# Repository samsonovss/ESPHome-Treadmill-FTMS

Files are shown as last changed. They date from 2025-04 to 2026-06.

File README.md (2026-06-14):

# Smart ESPHome Treadmill with FTMS and Native Zwift Incline Control

[Русская версия](README.ru.md) | [Releases and history](https://github.com/samsonovss/ESPHome-Treadmill-FTMS/releases) | [Telegram community](https://t.me/TreadmillSmart)

Turn an older treadmill into a modern smart training machine. This project completely replaces the original console with an ESP32-S3 and ESPHome solution, controls the lower motor board directly over UART, and connects to Zwift and other fitness applications through Bluetooth [Fitness Machine Service (FTMS)](docs/specs/FTMS_v1.0.pdf) without bridges or companion apps. It supports native incline control from Zwift, Home Assistant, a Nextion display, heart-rate programs, built-in workout modes, and user-position and safety-zone detection with a VL53L1X laser time-of-flight distance sensor. The current configuration was developed for PSA(xx)-family boards but can be adapted to other treadmills after their control protocol has been investigated.

https://github.com/user-attachments/assets/f829769c-47f4-4251-8f99-d2f9a6cf358a

## Highlights

- **Direct Bluetooth FTMS** - no bridges or companion apps;
- **Native Zwift incline control** - route grade physically controls the treadmill;
- **Home Assistant integration**;
- **Custom Home Assistant workout automations** - create and run your own speed and incline programs;
- **Nextion touchscreen interface**;
- **Heart-rate workouts, HIIT, warm-up, and cool-down**;
- **ESPHome-based and fully local** - no cloud required;
- **Laser ToF safety-zone detection, optical speed feedback, and motor-temperature monitoring**.

## Architecture

```mermaid
flowchart LR
    Apps[Zwift / Kinomap / other FTMS apps]
    HA[Home Assistant]
    HR[BLE heart-rate monitor]
    ESP[ESP32-S3 + ESPHome]
    Display[Nextion]
    Sensors[VL53L1X / FC-33 / DS18B20]
    Board[Treadmill motor controller]

    Apps <-->|BLE FTMS / RSC| ESP
    HA <-->|ESPHome API| ESP
    HR -->|BLE Heart Rate| ESP
    Display <-->|UART| ESP
    Sensors --> ESP
    ESP <-->|UART SETSPD / SETINC| Board
```

The ESP32-S3 acts as the central controller. It receives commands from the UI, workout programs, or fitness apps, sends them to the treadmill motor controller, and publishes telemetry back to Home Assistant and BLE clients.

## Supported Applications

Tested applications:

- **Zwift**
- **Kinomap** on Android and iOS
- **FitShow**
- **Kinni**

Other FTMS applications may behave differently. FTMS support alone does not guarantee that every application uses the same characteristics and control commands.

### Application Compatibility Matrix

| Feature | Zwift | Kinomap | FitShow | Kinni |
|---|---:|---:|---:|---:|
| Treadmill discovery over BLE | ✅ | ✅ | ✅ | ✅ |
| Speed reporting | ✅ | ✅ | ✅ | ✅ |
| Distance reporting | ✅ | ✅ | ✅ | ✅ |
| Heart-rate reporting | ✅ | ✅ | ✅ | ✅ |
| Start / pause / stop from the application | ➖ | ✅ | ✅ | ✅ |
| Target-speed control from the application | ➖ | ✅ | ✅ | ✅ |
| Incline control from the application | ➖ | ✅ | ✅ | ✅ |
| Automatic route-grade incline control | ✅ | ✅ | ✅ | ✅ |
| Native Zwift route-grade incline control | ✅ | ➖ | ➖ | ➖ |

✅ — tested and working; ➖ — not applicable.

> This matrix reflects practical testing with the current firmware version. Behavior may depend on the application version.

### FTMS and Zwift Compatibility

For standard fitness applications, the treadmill uses Bluetooth FTMS to report workout data and control speed and incline.

Native automatic incline in Zwift additionally uses a Wahoo KICKR RUN compatibility profile. Zwift sends route grade through the proprietary Wahoo Run service rather than through the standard FTMS incline-control command.

Therefore:

- standard FTMS provides primary compatibility with Zwift, Kinomap, FitShow, Kinni, and other applications;
- the Wahoo KICKR RUN profile provides native route-grade incline control in Zwift.

## Zwift Automatic Incline

The project supports two independent incline modes:

1. **Native Zwift incline**: the current route grade is received directly from Zwift and mapped to the treadmill's physical incline level.
2. **Standalone route profiles**: saved elevation profiles can run without the Zwift application.

Native mode provides:

- `Zwift Auto Incline` to enable physical incline control;
- `Treadmill Maximum Incline Level` for the treadmill controller limit;
- `Treadmill Real Grade At Maximum` for the measured real grade at that level;
- `Zwift Incline Intensity` for a 0-100% effect strength;
- `Zwift Requested Incline` for the grade received from Zwift;
- `Zwift Mapped Treadmill Incline` for the resulting treadmill target.

A treadmill value of `15` does not necessarily mean a real `15%` grade. Measure the actual belt rise and calibrate the mapping before enabling automatic incline.

See [Zwift setup and incline calibration](docs/guides/ZWIFT.md).

<details>
  <summary><b>Zwift demonstration</b></summary>
  <p align="center">
    Treadmill connected to Zwift
  </p>
</details>

## Treadmill Compatibility

The current configuration was developed for a treadmill with a PSA(xx)-family motor board accepting commands such as:

```text
[SETSPD:010]  -> 1.0 km/h
[SETINC:050]  -> incline level 5.0
```

Another treadmill can be adapted when its control interface is accessible, but the presence of UART does not make it automatically compatible. Voltage levels, baud rate, packet format, commands, feedback, and safe limits must be identified first.

See the [UART parsing guide](docs/guides/UART_PARSING.md).

> [!IMPORTANT]
> Reverse-engineering the control protocol is usually the most difficult part of adapting this project to another treadmill board.

## Hardware

Core components:

- ESP32-S3 with PSRAM and 16 MB Flash;
- treadmill with access to the lower motor controller interface;
- bidirectional logic-level converter;
- step-down power converter;
- Nextion `NX4880E043-011C`, 4.3-inch, 800 x 480 display;
- BLE heart-rate monitor.

Optional components:

- VL53L1X/TOF400C for Free Run, safe-zone detection, and display control;
- FC-33 for real-speed measurement and correction;
- DS18B20 for motor temperature monitoring;
- 3D-printed enclosure and mounts.

<details>
  <summary><b>Component photos</b></summary>
  <p align="center">
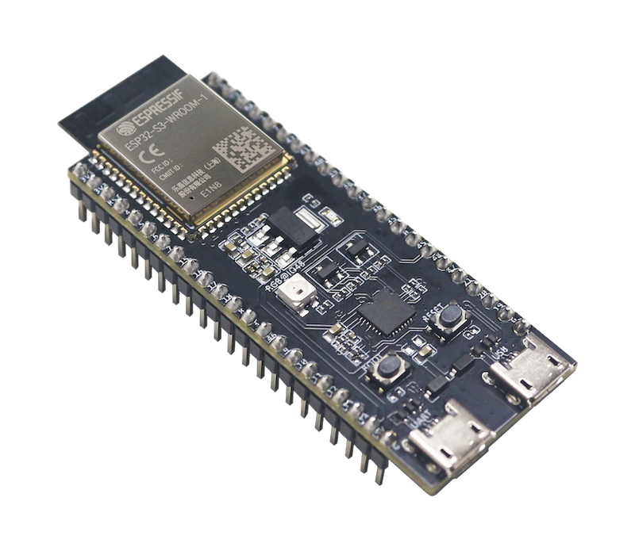
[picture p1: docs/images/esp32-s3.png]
ESP32-S3
    
    Nextion display
    VL53L1X
  </p>
  <p align="center">
    Logic-level converter
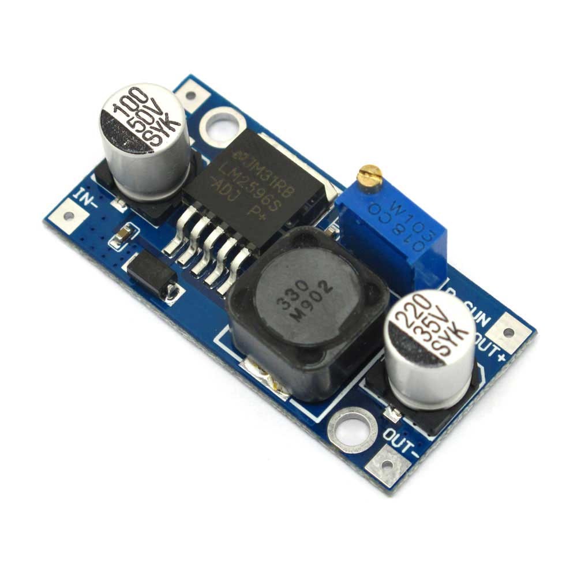
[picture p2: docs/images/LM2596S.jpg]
LM2596S step-down converter
    
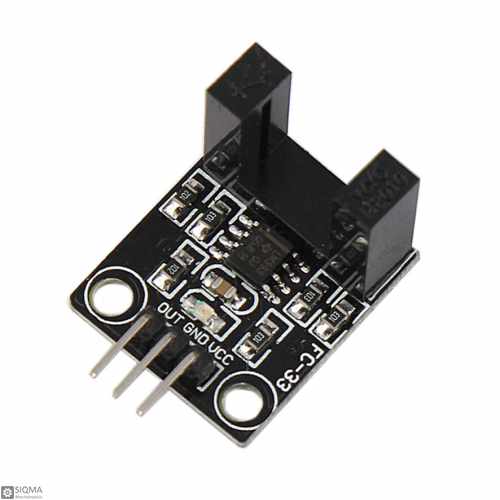
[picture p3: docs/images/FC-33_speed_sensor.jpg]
FC-33 optical sensor
    
  </p>
</details>

## Wiring

<p align="center">
  ESP32-S3 treadmill wiring diagram
</p>

Pins used by the current configuration:

| Function | ESP32-S3 |
|---|---|
| Nextion RX/TX | GPIO1 / GPIO2 |
| Treadmill board TX/RX | GPIO17 / GPIO18 |
| I2C SDA/SCL | GPIO12 / GPIO11 |

Verify the voltage levels of your motor board before connecting it. Never feed 5 V or 12 V directly into ESP32-S3 GPIO pins.

## Quick Start

1. Download the repository and copy the contents of `esphome/` into your ESPHome configuration directory.
2. Rename `secrets.example.yaml` to `secrets.yaml`.
3. Configure Wi-Fi, API, OTA, fallback access point, DS18B20 address, heart-rate monitor MAC, and Nextion TFT URL.
4. Keep the `packages/` directory next to `config.yaml`; the main file loads all functional sections from it.
5. Verify pin assignments, UART settings, and the command format used by your treadmill.
6. Disconnect the power stage and first test ESP32 boot, Nextion, and sensors.
7. Create a backup, compile the configuration, and inspect the logs.
8. Test stop behavior, minimum speed, and incline reset without a person on the belt.

The configuration is a working example for one installation, not a universal firmware image for every treadmill.

## Workout Modes

- manual control;
- Pulse Zone;
- Fat Burn;
- Recovery Run;
- configurable HIIT work and recovery cycles;
- warm-up and cool-down;
- distance-based Free Run;
- precomputed route elevation profiles;
- native Zwift incline control.

Configurable treadmill behavior profiles:

- **Speed correction:** `Soft`, `Precise`, and `Aggressive` control how actively the system compensates for differences between the target and measured belt speed;
- **Acceleration and deceleration:** `Soft`, `Normal`, `Fast`, and `Technogym` control how smoothly and quickly the belt changes speed.

## Interfaces

The local ESPHome web interface is available on port `80` without authentication.

Workout recording to CSV and Garmin FIT is available through the optional [Home Assistant workout recorder](treadmill_workouts/README.md).

### Home Assistant

<p align="center">
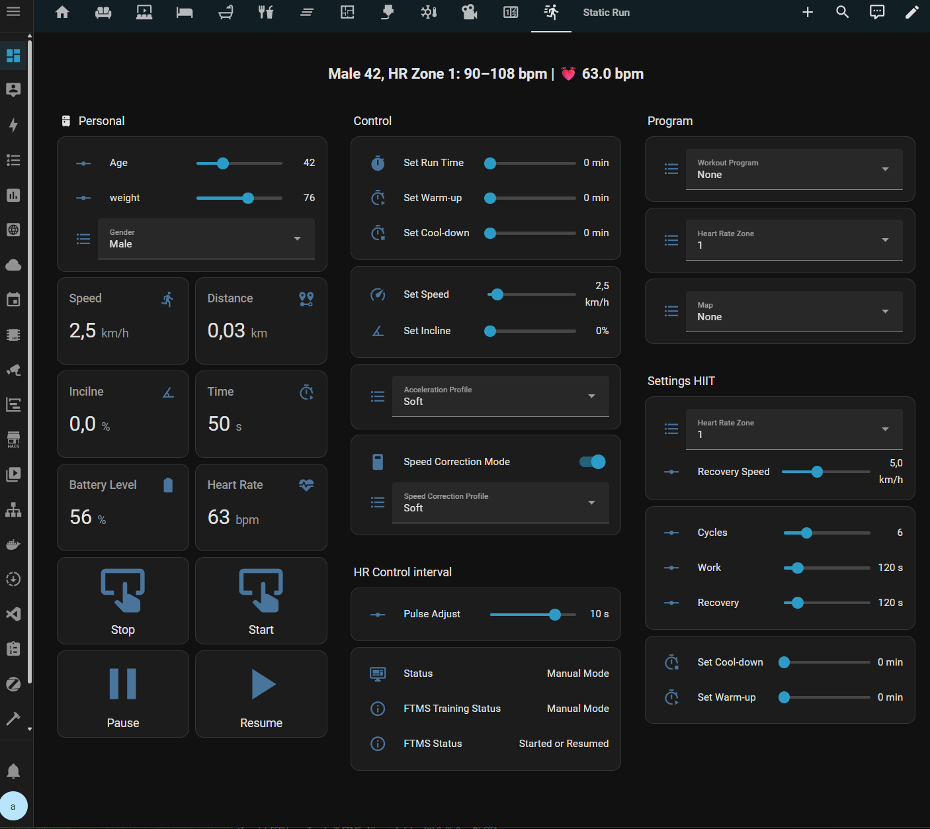
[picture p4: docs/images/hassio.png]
Home Assistant treadmill control interface
  
</p>

<details>
  <summary><b>Nextion</b></summary>
  <p align="center">
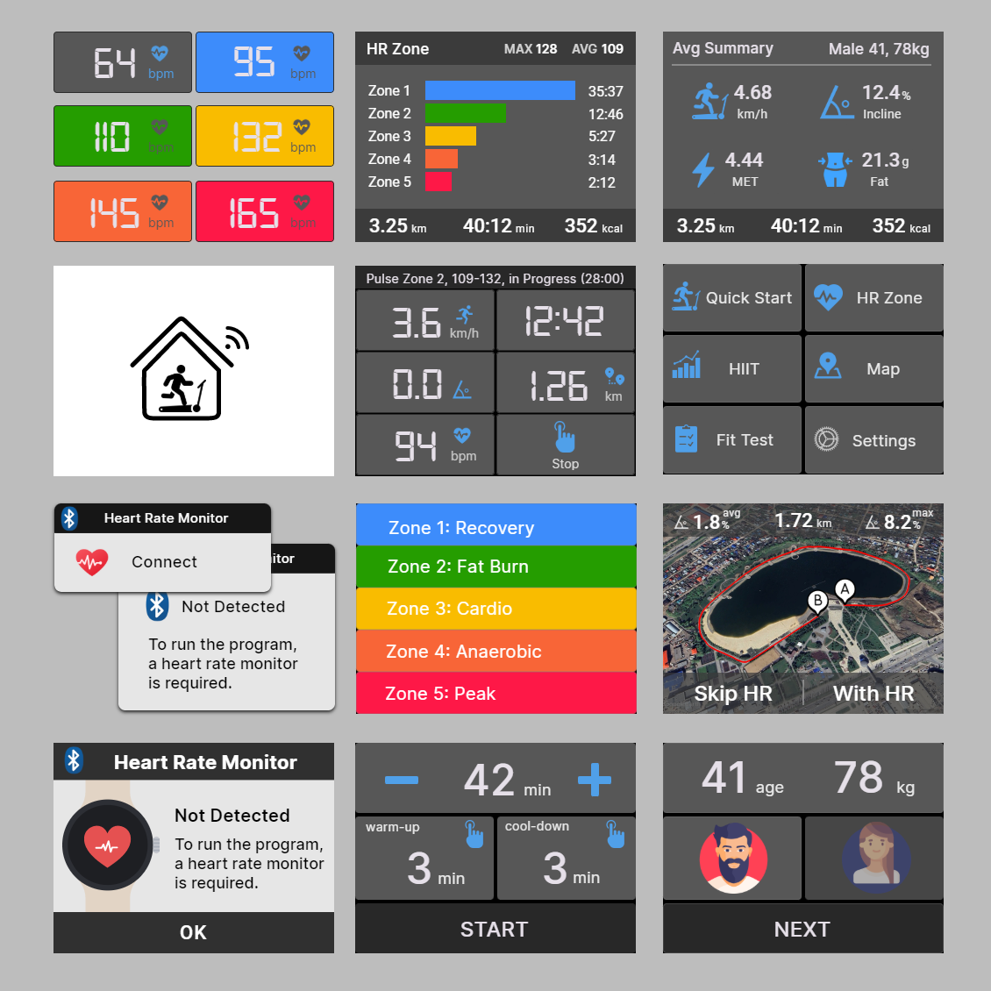
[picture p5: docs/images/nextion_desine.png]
Nextion display interface
    
  </p>
</details>

<details>
  <summary><b>Finished treadmill gallery</b></summary>
  <p align="center">
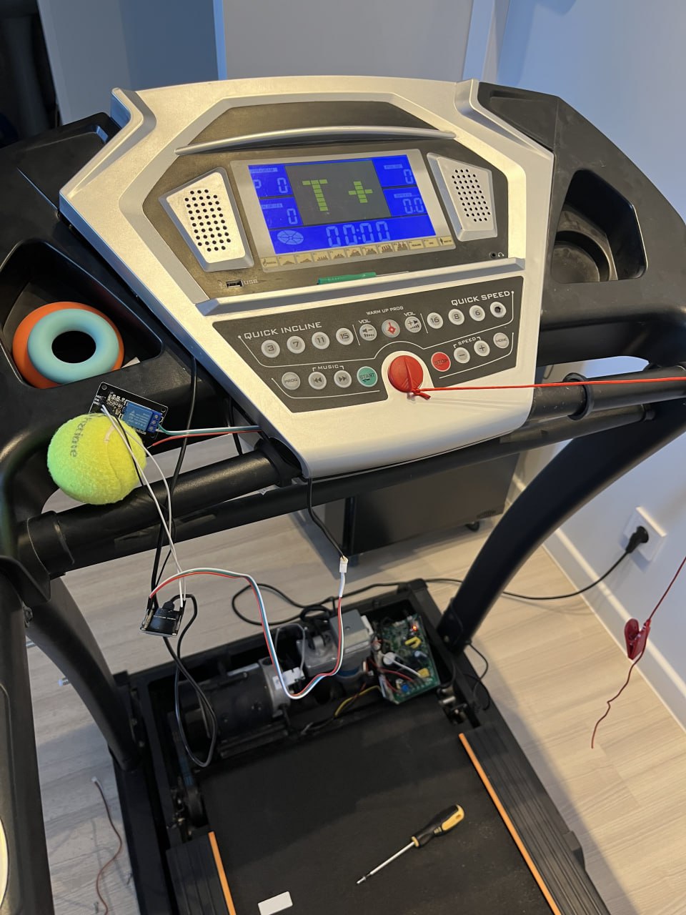
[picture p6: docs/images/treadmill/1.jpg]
Finished treadmill, view 1
    
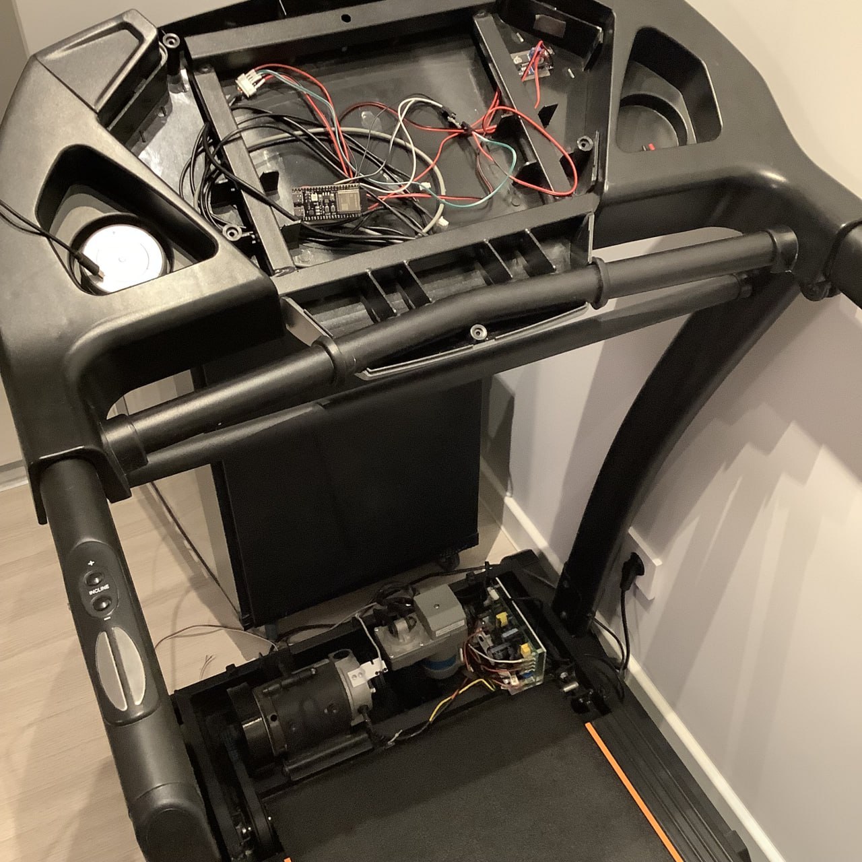
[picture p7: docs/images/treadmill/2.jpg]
Finished treadmill, view 2
    
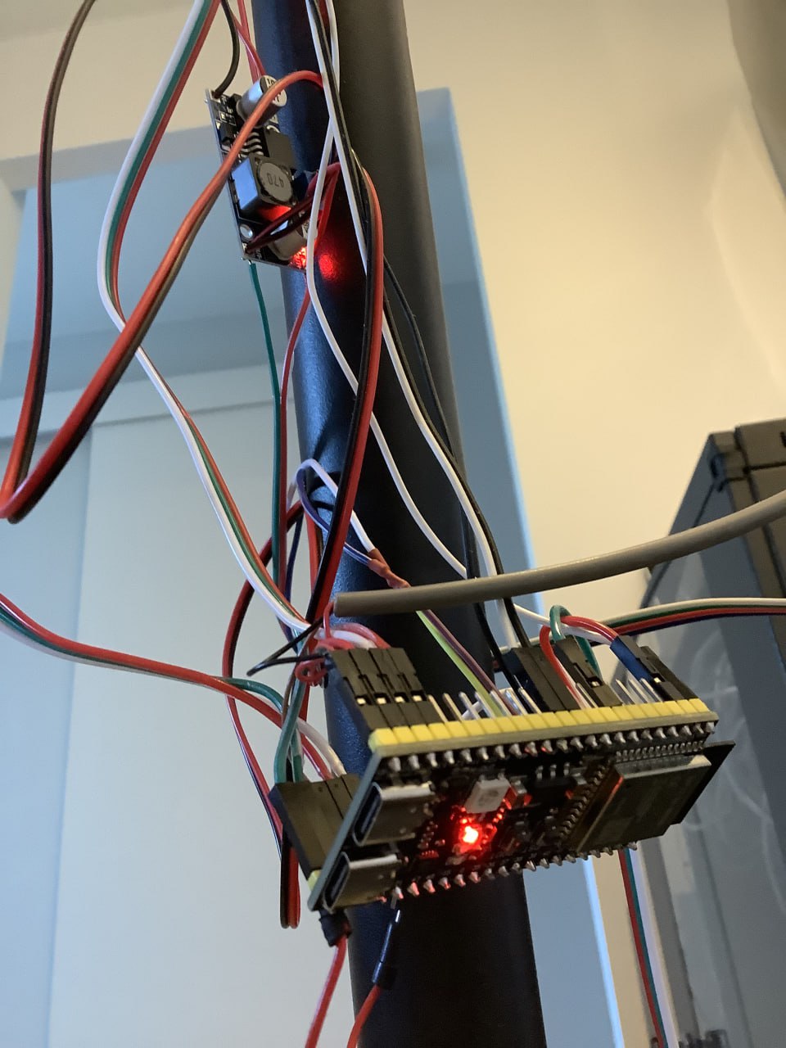
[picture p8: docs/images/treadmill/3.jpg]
Finished treadmill, view 3
    
  </p>
  <p align="center">
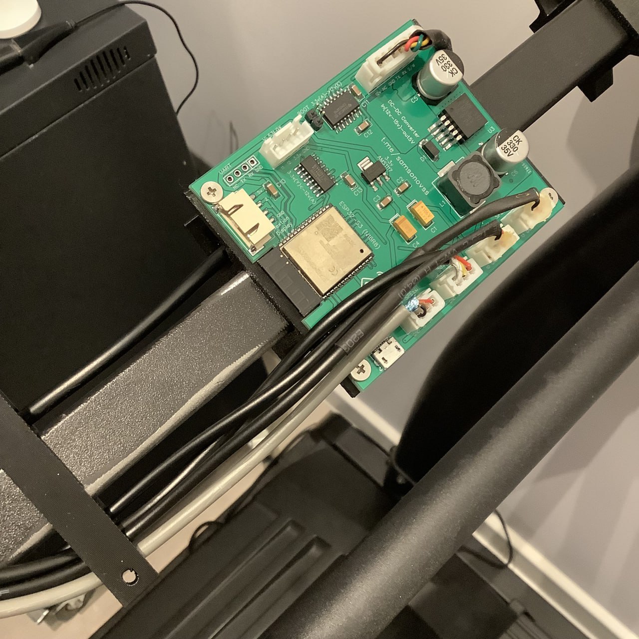
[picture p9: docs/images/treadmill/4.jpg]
Finished treadmill, view 4
    
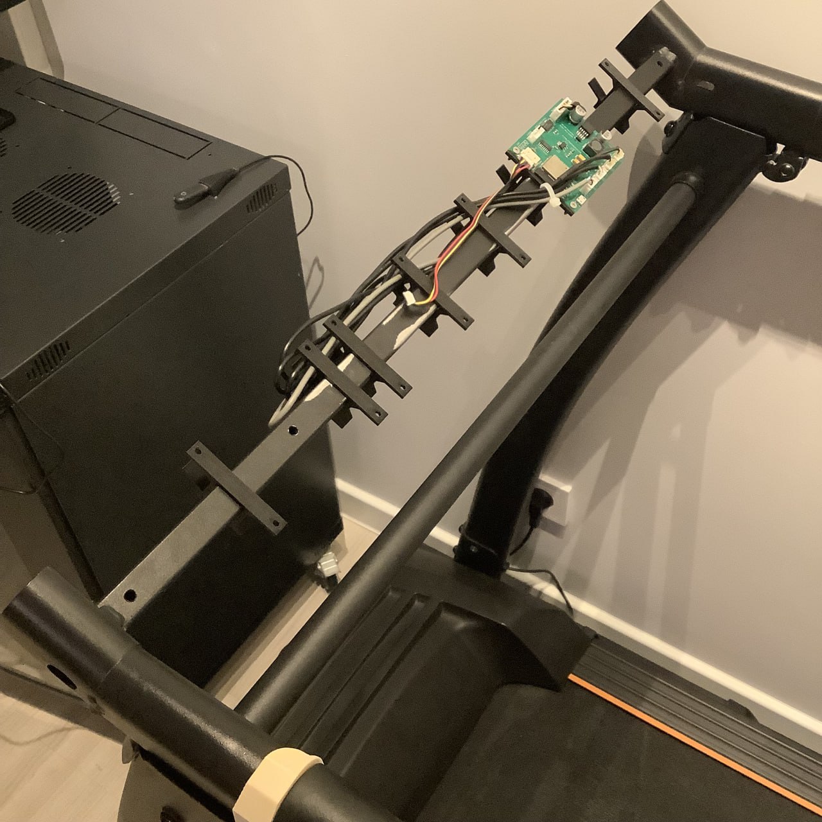
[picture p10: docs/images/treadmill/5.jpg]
Finished treadmill, view 5
    
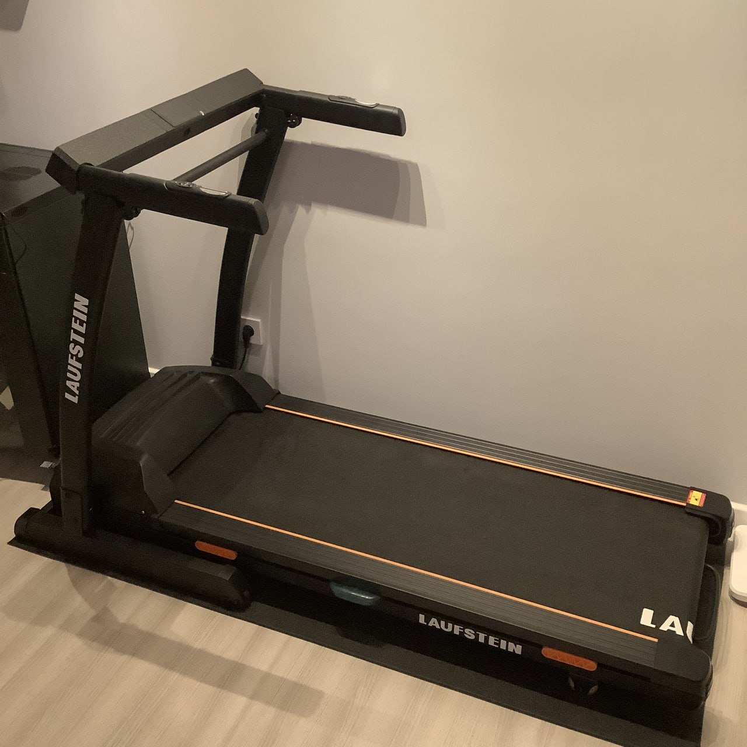
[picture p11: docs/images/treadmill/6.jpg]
Finished treadmill, view 6
    
  </p>
</details>

Videos:

- [control dashboard overview](https://youtube.com/shorts/wjRsA46usog);
- [treadmill running demonstration](https://youtube.com/shorts/QqvJLKn4GOk).

## Repository Layout

- [`esphome/config.yaml`](esphome/config.yaml) - main device configuration with ESP32, network, API, OTA, BLE, and package declarations;
- [`esphome/packages/`](esphome/packages/) - hardware, globals, scripts, sensors, BLE/FTMS, controls, and Nextion configuration;
- [`esphome/incline_profiles.h`](esphome/incline_profiles.h) - generated route incline profiles;
- [`treadmill_workouts/`](treadmill_workouts/) - Home Assistant CSV recorder and FIT exporter;
- [`nextion_display/`](nextion_display/) - display source, HMI, and compiled TFT;
- [`route_profiles/`](route_profiles/) - optional GPX sources, saved route profiles, and profile-generation tools;
- [`3d-models/`](3d-models/) - printable enclosure and sensor mounts;
- [`PCB/`](PCB/) - future PCB design materials;
- [`docs/guides/`](docs/guides/) - detailed setup guides;
- [`docs/specs/FTMS_v1.0.pdf`](docs/specs/FTMS_v1.0.pdf) - FTMS specification;
- [GitHub Releases](https://github.com/samsonovss/ESPHome-Treadmill-FTMS/releases) - versions and project history.

## Roadmap

- cadence measurement.
- feasibility study for a custom lower power board controlling the treadmill motor and incline.

Completed work is removed from the roadmap and recorded in the [release notes](https://github.com/samsonovss/ESPHome-Treadmill-FTMS/releases).

## Support the Project

This project is developed in the author's free time and has so far been funded personally. Firmware and electronics development, prototype manufacturing, components, and testing require significant time and expense.

If this project has been useful to you and you would like to support its continued development, any contribution will help fund new components, prototypes, test equipment, and documentation.

## Author and Community

Created by [Anton Samsonov](https://t.me/samsonovss).

Discussion, builds, and support: [Treadmill Smart](https://t.me/TreadmillSmart).

## Support the Project

- PayPal: `samsonov@hotmail.com`
- BTC: `bc1q3cza0kasutzes4hfddxuclmd9ghn5v7zw2nr5c`

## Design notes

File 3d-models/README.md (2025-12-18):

# 3D Printed Enclosure

This folder contains the 3D model of the enclosure and the small mounting parts used for installing the speed‑sensor module.

<p align="center">
  
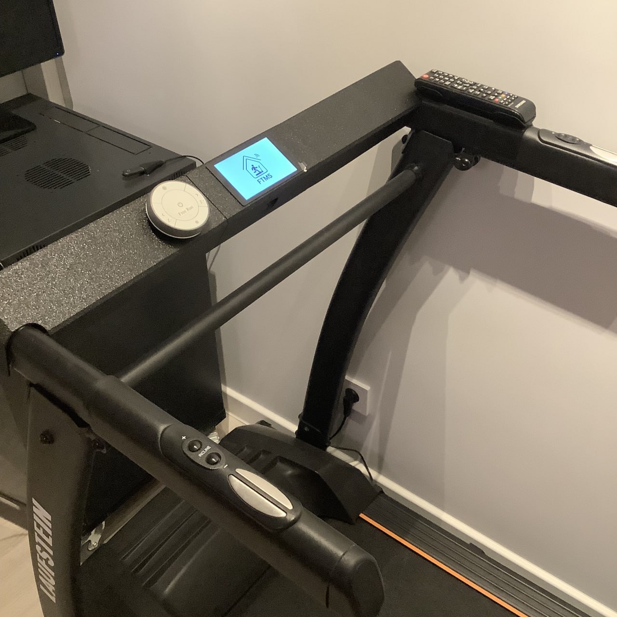
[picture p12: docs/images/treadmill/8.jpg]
  
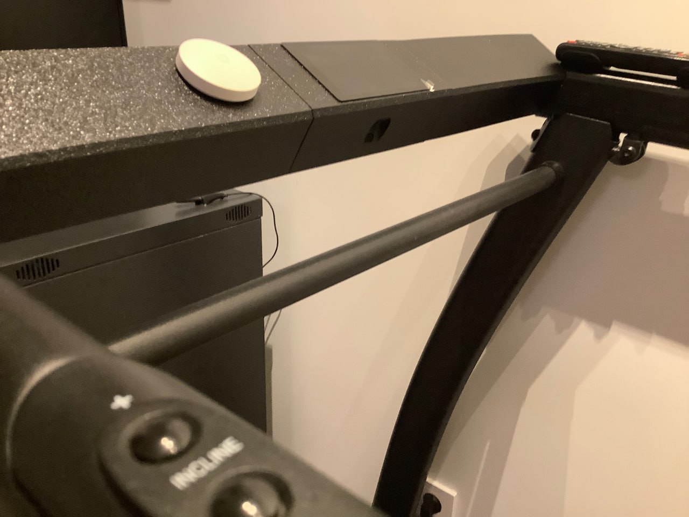
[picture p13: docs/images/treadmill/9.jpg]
  
</p>

## 🎯 Design Philosophy

The goal of this project was to create a clean, minimalist enclosure instead of the bulky, outdated “modern” designs commonly found in treadmill accessories.  
The envisioned setup includes a sleek control panel with a display, an optional tablet mount with wireless charging, and a large wall‑mounted TV for training apps — all designed to look simple, elegant, and unobtrusive.

## 📦 Enclosure Overview

The design consists of three separate parts, which are assembled together and mounted on top of the treadmill’s control module.

In the lower section of the enclosure, a distance sensor is installed.  
It enables the free‑run mode, automatically activates the display, and controls the treadmill speed based on the measured distance.

Under the top panel, a magnet is permanently fixed, allowing you to attach any magnetic button on top of the enclosure.  
You can program this button for any custom action depending on your ESPHome configuration.

The enclosure is planned to support additional upgrades in future revisions, such as:

- a tablet mount installed on top of the enclosure  
- a wireless charging pad placed underneath the tablet holder  

These features will be useful if you want to use a tablet for Zwift, YouTube, or other training applications.

## ⚠️ Design Status

The current STEP model is not fully finished.  
At this stage, the enclosure does not yet include the bottom cover.  
These components will be added in future revisions of the design.

## 🖨️ 3D Printing Details

- Printed on Bambu Lab A1  
- Print area used: 256 × 256 × 256 mm  
- Surface printed using fuzzy skin

## 🎨 Finishing (Optional)

If desired, the enclosure can be:

- sanded  
- primed  
- painted  

This allows you to achieve a smooth, durable, and professional‑looking finish.

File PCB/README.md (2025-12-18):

## PCB Design for ESPHome Treadmill-Zwift

This directory is intended to store the design files and documentation for the future custom printed circuit board (PCB) for the ESPHome Treadmill-Zwift project, which will be developed using EasyEDA.

<p align="center">
  
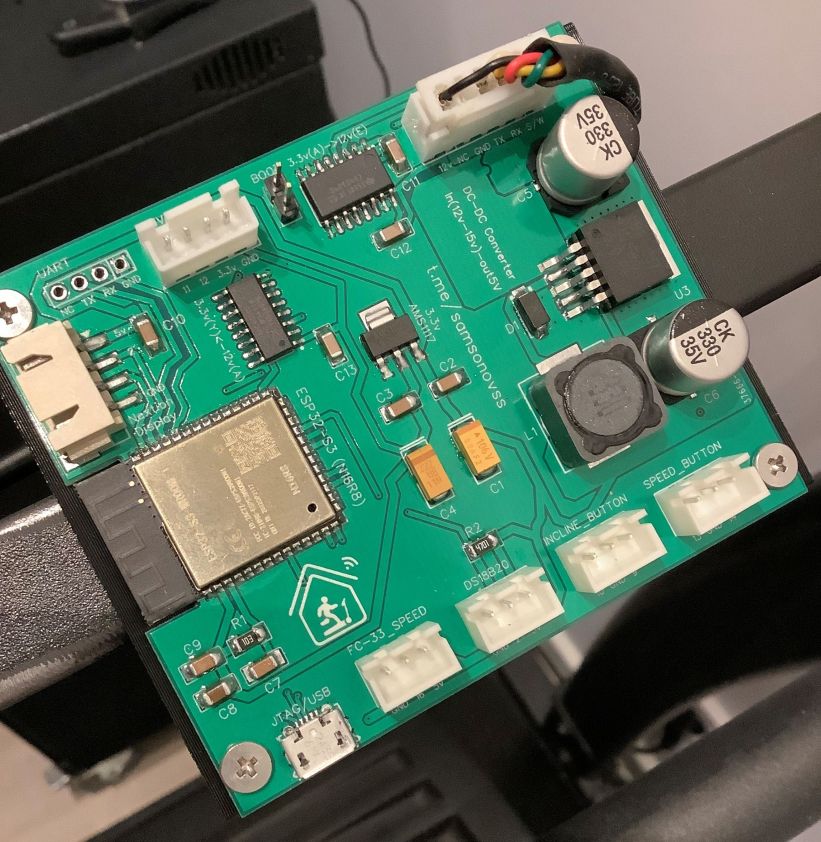
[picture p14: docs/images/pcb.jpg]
  
</p>

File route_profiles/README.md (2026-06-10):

# Route Profiles

[Русская версия](README.ru.md)

This directory contains source route data and development tools used to prepare
autonomous treadmill incline profiles.

It is **not required for a normal ESPHome installation**. The profiles used by
the firmware are already stored in [`esphome/incline_profiles.h`](../esphome/incline_profiles.h).

## Directory Layout

```text
route_profiles/
├── gpx_files/       # Source GPX routes with distance and elevation waypoints
├── scripts/         # GPX conversion tools
└── zwift_profiles/  # Saved Zwift route profiles and generated C++ snippets
```

## Preparing a Route

1. Create or export a route as KML or GPX.
2. If elevation data is missing, process it with
   [GPS Visualizer](https://www.gpsvisualizer.com/convert_input):
   - output format: `GPX`;
   - DEM elevation data: `Best available source`;
   - equal-interval waypoints: `30 meters`.
3. Save the result in `route_profiles/gpx_files/`.
4. Run the converter from the repository root:

   ```sh
   python3 route_profiles/scripts/gpx_to_incline_profile.py \
     route_profiles/gpx_files/example.gpx \
     --name example_route
   ```

By default, the generated C++ profile is written next to the input file as
`example.profile.h`. Use `--output` to choose another path.

The generated file contains a two-dimensional ESPHome profile:

```cpp
const float incline_profile_example_route[][2] PROGMEM = {
  {0.000, 0},
  {0.030, 3},
};
```

The first value is route distance in kilometres. The second value is the
treadmill incline level.

## Calibration

The default conversion assumes:

```text
maximum treadmill level = 15
real grade at maximum = 5%
```

Override these values when your treadmill uses different limits:

```sh
python3 route_profiles/scripts/gpx_to_incline_profile.py \
  route_profiles/gpx_files/example.gpx \
  --name example_route \
  --maximum-level 15 \
  --real-grade-at-maximum 5
```

Review the generated profile before copying it into
`esphome/incline_profiles.h`. The converter intentionally never overwrites the
firmware profile file automatically.

## GPX Requirements

The converter expects GPX waypoints containing:

- an `<ele>` elevation value;
- a `<name>` beginning with distance in metres and containing the word
  `distance`.

GPS Visualizer can create waypoints in this format.

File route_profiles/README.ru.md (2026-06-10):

# Профили маршрутов

[English version](README.md)

Этот каталог содержит исходные маршруты и инструменты разработки для
подготовки автономных профилей наклона беговой дорожки.

Для обычной установки ESPHome он **не требуется**. Готовые профили, которые
использует прошивка, уже находятся в
[`esphome/incline_profiles.h`](../esphome/incline_profiles.h).

## Структура

```text
route_profiles/
├── gpx_files/       # Исходные GPX с точками дистанции и высоты
├── scripts/         # Инструменты преобразования GPX
└── zwift_profiles/  # Сохранённые профили Zwift и фрагменты C++
```

## Подготовка маршрута

1. Создайте или экспортируйте маршрут в KML либо GPX.
2. Если в файле нет высоты, обработайте его через
   [GPS Visualizer](https://www.gpsvisualizer.com/convert_input):
   - формат результата: `GPX`;
   - данные высоты DEM: `Best available source`;
   - точки с равным интервалом: `30 meters`.
3. Сохраните результат в `route_profiles/gpx_files/`.
4. Запустите конвертер из корня репозитория:

   ```sh
   python3 route_profiles/scripts/gpx_to_incline_profile.py \
     route_profiles/gpx_files/example.gpx \
     --name example_route
   ```

По умолчанию рядом с исходным файлом будет создан
`example.profile.h`. Другой путь можно указать через `--output`.

Результат имеет тот же двумерный формат, который использует ESPHome:

```cpp
const float incline_profile_example_route[][2] PROGMEM = {
  {0.000, 0},
  {0.030, 3},
};
```

Первое значение — пройденная дистанция в километрах, второе — уровень наклона
дорожки.

## Калибровка

По умолчанию используется соответствие:

```text
максимальный уровень дорожки = 15
реальный уклон на максимуме = 5%
```

Для другой дорожки задайте собственные значения:

```sh
python3 route_profiles/scripts/gpx_to_incline_profile.py \
  route_profiles/gpx_files/example.gpx \
  --name example_route \
  --maximum-level 15 \
  --real-grade-at-maximum 5
```

Проверьте созданный профиль перед переносом в
`esphome/incline_profiles.h`. Конвертер специально не перезаписывает рабочий
файл прошивки автоматически.

## Требования к GPX

Конвертер ожидает точки `<wpt>`, содержащие:

- высоту в поле `<ele>`;
- поле `<name>`, которое начинается с дистанции в метрах и содержит слово
  `distance`.

Такие точки умеет создавать GPS Visualizer.

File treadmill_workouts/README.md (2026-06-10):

# Treadmill Workout Recorder

This optional Home Assistant companion records treadmill workouts to CSV and exports a Garmin FIT activity after each workout.

## How It Works

1. A Home Assistant automation starts `treadmill_recorder.py` when `binary_sensor.treadmill_treadmill_usage` turns on.
2. The recorder reads treadmill entities from the local Home Assistant REST API once per second.
3. Samples are written to a timestamped CSV file.
4. When the treadmill stops, the recorder writes a summary JSON file.
5. `treadmill_fit_export.py` converts the CSV and summary into a FIT running activity with treadmill sub-sport.

The FIT exporter uses only the Python standard library. It writes timestamps, heart rate, speed, distance, incline/grade, calories, lap, session, and activity summaries.

## Directory Layout

```text
/config/treadmill_workouts/
├── scripts/
│   ├── treadmill_recorder.py
│   └── treadmill_fit_export.py
├── secrets/
│   └── .ha_token
├── workouts/
├── logs/
└── state/
```

The repository contains empty runtime directories. Tokens, logs, state files, and personal workout exports are excluded by `.gitignore`.

## Installation

1. Copy `treadmill_workouts/` to `/config/treadmill_workouts/` in Home Assistant.
2. Make the scripts executable:

   ```sh
   chmod 755 /config/treadmill_workouts/scripts/*.py
   ```

3. In the Home Assistant user profile, create a long-lived access token.
4. Save only the token value to:

   ```text
   /config/treadmill_workouts/secrets/.ha_token
   ```

5. Restrict access to the token:

   ```sh
   chmod 600 /config/treadmill_workouts/secrets/.ha_token
   ```

6. Merge [`examples/configuration.yaml`](examples/configuration.yaml) into `configuration.yaml`.
7. Add [`examples/automations.yaml`](examples/automations.yaml) through YAML or recreate the three automations in the Home Assistant UI.
8. Check the configuration and restart Home Assistant.

## Configuration

Edit these constants in `scripts/treadmill_recorder.py` when your installation uses different values:

- `BASE_URL` - local Home Assistant URL;
- `ROOT` - recorder directory;
- `TZ` - workout timezone;
- `LIVE_ENTITIES` - entities sampled every second;
- `SUMMARY_ENTITIES` - final workout statistics.

The supplied entity IDs match this treadmill project.

## Output

Each workout creates:

```text
YYYY-MM-DD_HH-MM-SS.csv
YYYY-MM-DD_HH-MM-SS.summary.json
YYYY-MM-DD_HH-MM-SS.fit
```

CSV columns:

```text
timestamp, heart_rate, speed_kmh, incline_pct, distance_km,
time_s, calories, status, program, zone
```

The FIT file can be imported into applications that accept standard FIT running activities.

## Manual Use

```sh
python3 /config/treadmill_workouts/scripts/treadmill_recorder.py start
python3 /config/treadmill_workouts/scripts/treadmill_recorder.py stop
python3 /config/treadmill_workouts/scripts/treadmill_recorder.py status
```

Convert an existing CSV manually:

```sh
python3 \
  /config/treadmill_workouts/scripts/treadmill_fit_export.py \
  workout.csv workout.summary.json workout.fit
```

Logs are written to `/config/treadmill_workouts/logs/recorder.log`.

## Privacy

Do not commit `.ha_token`, CSV, FIT, summary, state, or log files. Workout exports may contain timestamps, heart rate, speed, distance, and other personal activity data.

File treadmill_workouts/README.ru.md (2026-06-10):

# Запись тренировок беговой дорожки

Это дополнительный модуль Home Assistant, который записывает тренировки в CSV и после остановки создаёт файл активности Garmin FIT.

## Как это работает

1. Автоматизация Home Assistant запускает `treadmill_recorder.py`, когда `binary_sensor.treadmill_treadmill_usage` переходит в состояние `on`.
2. Раз в секунду скрипт получает значения сущностей через локальный REST API Home Assistant.
3. Измерения записываются в CSV с датой и временем в имени.
4. После остановки дорожки создаётся итоговый JSON.
5. `treadmill_fit_export.py` преобразует CSV и JSON в FIT-активность типа «бег на дорожке».

Экспортёр FIT использует только стандартную библиотеку Python. В файл записываются время, пульс, скорость, дистанция, наклон, калории и итоговые сообщения lap/session/activity.

## Структура каталога

```text
/config/treadmill_workouts/
├── scripts/
│   ├── treadmill_recorder.py
│   └── treadmill_fit_export.py
├── secrets/
│   └── .ha_token
├── workouts/
├── logs/
└── state/
```

В репозитории runtime-каталоги пустые. Токены, логи, состояние и личные файлы тренировок исключены через `.gitignore`.

## Установка

1. Скопируйте `treadmill_workouts/` в `/config/treadmill_workouts/` Home Assistant.
2. Сделайте скрипты исполняемыми:

   ```sh
   chmod 755 /config/treadmill_workouts/scripts/*.py
   ```

3. Создайте долгоживущий токен в профиле пользователя Home Assistant.
4. Сохраните только значение токена в файл:

   ```text
   /config/treadmill_workouts/secrets/.ha_token
   ```

5. Ограничьте доступ к нему:

   ```sh
   chmod 600 /config/treadmill_workouts/secrets/.ha_token
   ```

6. Добавьте содержимое [`examples/configuration.yaml`](examples/configuration.yaml) в `configuration.yaml`.
7. Добавьте [`examples/automations.yaml`](examples/automations.yaml) в YAML автоматизаций или создайте три автоматизации через интерфейс Home Assistant.
8. Проверьте конфигурацию и перезапустите Home Assistant.

## Настройка

Если ваша установка отличается, измените константы в `scripts/treadmill_recorder.py`:

- `BASE_URL` — локальный адрес Home Assistant;
- `ROOT` — каталог рекордера;
- `TZ` — часовой пояс тренировки;
- `LIVE_ENTITIES` — сущности, опрашиваемые каждую секунду;
- `SUMMARY_ENTITIES` — итоговые показатели тренировки.

Указанные в скрипте entity_id соответствуют этому проекту дорожки.

## Результат

Для каждой тренировки создаются:

```text
YYYY-MM-DD_HH-MM-SS.csv
YYYY-MM-DD_HH-MM-SS.summary.json
YYYY-MM-DD_HH-MM-SS.fit
```

Столбцы CSV:

```text
timestamp, heart_rate, speed_kmh, incline_pct, distance_km,
time_s, calories, status, program, zone
```

FIT можно импортировать в приложения, поддерживающие стандартные FIT-активности.

## Ручной запуск

```sh
python3 /config/treadmill_workouts/scripts/treadmill_recorder.py start
python3 /config/treadmill_workouts/scripts/treadmill_recorder.py stop
python3 /config/treadmill_workouts/scripts/treadmill_recorder.py status
```

Ручное преобразование существующего CSV:

```sh
python3 \
  /config/treadmill_workouts/scripts/treadmill_fit_export.py \
  workout.csv workout.summary.json workout.fit
```

Лог находится в `/config/treadmill_workouts/logs/recorder.log`.

## Конфиденциальность

Не публикуйте `.ha_token`, CSV, FIT, summary, state и log-файлы. Экспорт тренировок может содержать время, пульс, скорость, дистанцию и другие личные данные.

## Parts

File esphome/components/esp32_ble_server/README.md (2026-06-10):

# Patched ESPHome BLE Server Component

This directory vendors the `esp32_ble_server` component from ESPHome 2026.5.3.

Source:

<https://github.com/esphome/esphome/tree/2026.5.3/esphome/components/esp32_ble_server>

## Local modification

Only `ble_characteristic.cpp` differs from the upstream 2026.5.3 component.

ESPHome 2026.5.3 changes subscribed Indicate messages into unconfirmed Notify messages. Zwift requires a confirmed FTMS Control Point response before it accepts the treadmill as a controllable device.

The local patch preserves the client's CCCD choice:

- Notify subscriptions use unconfirmed notifications;
- Indicate subscriptions use confirmed indications;
- the ESP-IDF GATT server handles the confirmation exchange.

Remove the local component and the matching `external_components` entry when the upstream ESPHome implementation supports confirmed indications for this use case.

## License

The vendored files retain the ESPHome licensing model:

- Python and other non-runtime files: MIT;
- C/C++ runtime files: GPLv3.

See [LICENSE](LICENSE).

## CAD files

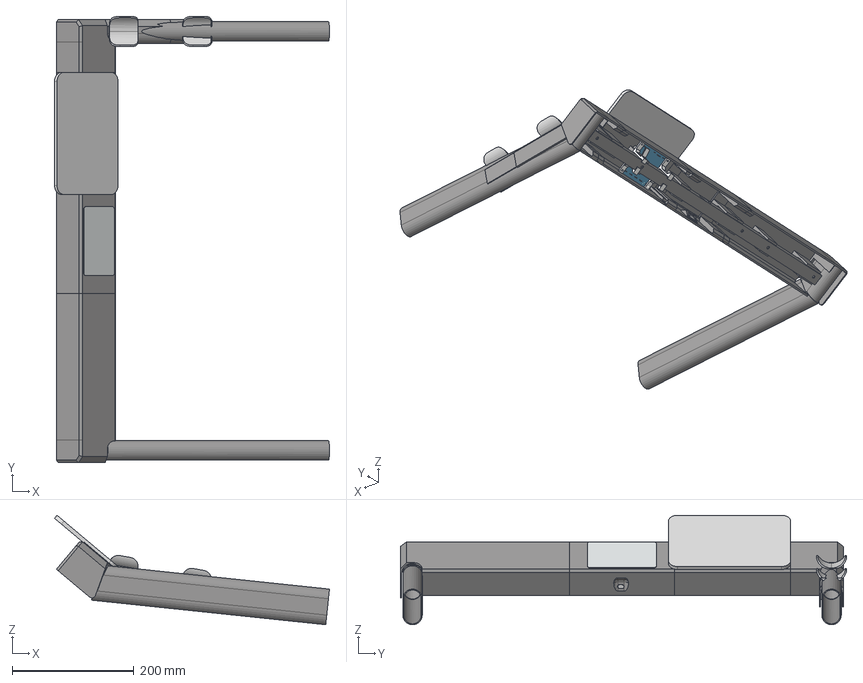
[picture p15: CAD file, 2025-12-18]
3d-models/treadmill_case.step
450.9 x 731.8 x 179.4 mm

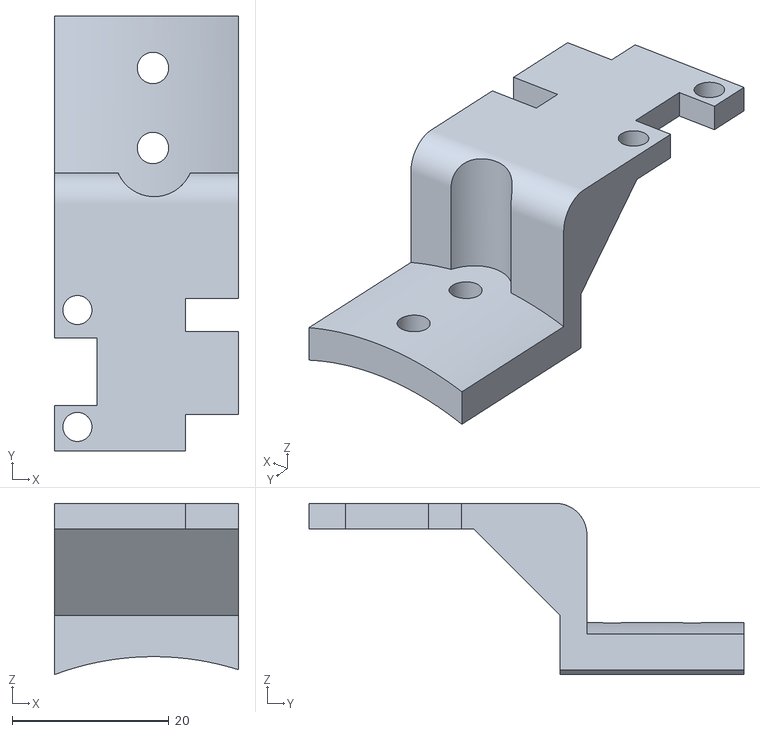
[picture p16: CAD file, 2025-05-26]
3d-models/FC33_speed_sensor_mount_v2.stl
23.4 x 55.4 x 21.8

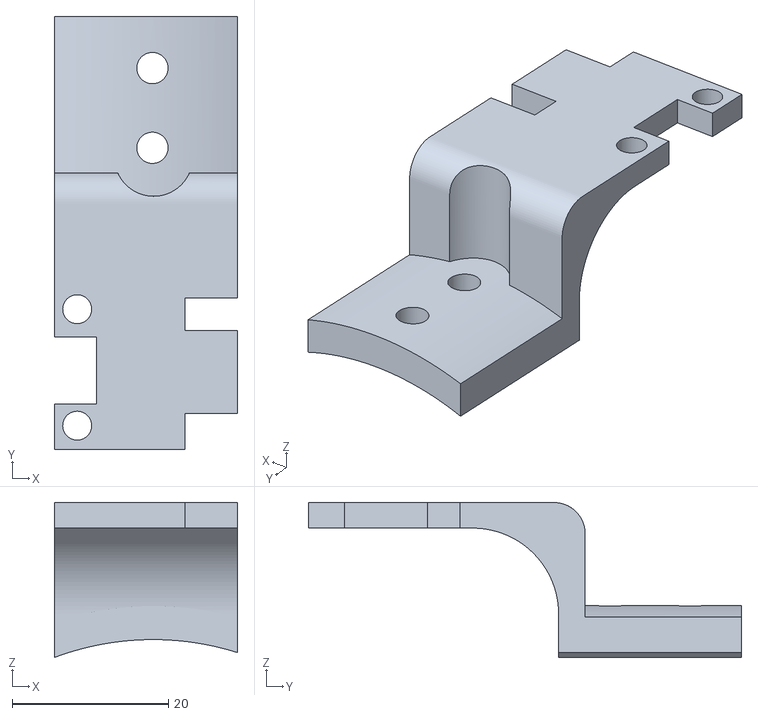
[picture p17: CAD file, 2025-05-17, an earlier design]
3d-models/FC33_speed_sensor_mount.stl
23.4 x 55.4 x 19.8

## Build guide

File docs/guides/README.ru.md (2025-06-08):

# Полная реализация бортового компьютера беговой дорожки на базе ESPHome

Превратите старую беговую дорожку в современного умного помощника для тренировок! Этот проект — полноценная замена бортового компьютера на базе ESP32-S3 и прошивки ESPHome. Он добавляет поддержку протокола [Fitness Machine Service (FTMS)](/docs/specs/FTMS_v1.0.pdf) для прямого общения тренажёра с фитнес-приложениями через Bluetooth, без необходимости в мостах и сторонних приложениях. Также включает интеллектуальные программы на основе пульса и встроенные тренировочные режимы. Разработан для дорожек с платами PSA(xx), но адаптируется к любой модели с UART. Минимум затрат — максимум возможностей!

### Поддерживаемые FTMS-приложения
- :white_check_mark: Zwift
- :white_check_mark: Kinomap (Android/iOS)
- :white_check_mark: FitShow
- :white_check_mark: Kinni
- :white_check_mark: qdomyos

**[English version](/README.md)**

## Оглавление
- [О проекте](#О-проекте)
- [Как это работает](#как-это-работает)
- [UART парсинг](UART_PARSING.ru.md)
- [Рекомендуемое оборудование](#рекомендуемое-оборудование)
- [Подключение](#подключение)
- [Функции](#функции)
- [Настройка ESPHome](#настройка-esphome)
- [Пример результатов тренировки](#пример-результатов-тренировки)
- [Планы развития](#Планы-развития)
- [История изменений](/CHANGELOG.md)

## О проекте
- **Цель**: Заменить устаревший бортовой компьютер беговой дорожки на современное решение.
- **Ключевые особенности**:
  - Полная реализация бортового компьютера на ESP32-S3 с прошивкой ESPHome.
  - Интеграция протокола [Fitness Machine Service (FTMS)](/docs/specs/FTMS_v1.0.pdf) для прямого подключения к фитнес-приложениям (Zwift, Kinomap и др.) через Bluetooth Low Energy (BLE) без посредников.
  - Минималистичный дизайн с компактным экраном (Nextion), отображающим скорость, время и дистанцию, не перекрываемым планшетом.
  - Поддержка UART для связи с платой дорожки, например, PSA(xx).
  - Интеллектуальные алгоритмы регулировки скорости и наклона на основе данных пульсометра.

## Как это работает
Проект использует ESP32-S3 для связи с платой беговой дорожки (например, PSA(xx)) через UART. Команды вроде `[SETSPD:010]` (1 км/ч) или `[SETINC:000]` (0%) были расшифрованы путём анализа трафика с помощью [UART-логгера](UART_PARSING.ru.md). Микроконтроллер обрабатывает эти данные, преобразует их в реальные значения скорости и наклона, а затем передаёт через Bluetooth Low Energy (BLE) в приложения, такие как Zwift, или сохраняет локально для анализа в Grafana.

Пульсометр подключается через BLE и передаёт данные о пульсе. Интеллектуальные алгоритмы в реальном времени анализируют пульс и плавно регулируют настройки дорожки, чтобы поддерживать заданную тренировочную зону. Например, если пульс выходит за пределы цели, скорость автоматически корректируется для индивидуальной и эффективной тренировки.

## Важный момент: Почему я убрал верхний бортовой компьютер
- **Проблемы с оригинальным бортовым компьютером**:
  1. **Конфликт команд**: При попытке отправлять команды с верхнего бортового компьютера напрямую к нижней плате они успешно передаются, но верхняя плата продолжает слать свои данные, перебивая мои команды.
     - Решение: Отправлять команды по UART на верхнюю плату, чтобы она задавала скорость и наклон, а затем передавала их нижней. Однако я не смог реализовать отправку данных на верхнюю плату. Вместо этого команды успешно и просто передаются напрямую на нижнюю плату.
  2. **Устаревший дизайн**: Оригинальный бортовой компьютер громоздкий, занимает много места. Удобно класть планшет, но он перекрывает дисплей с данными о скорости, наклоне и дистанции.
- **Моё решение**:
  - Полностью убрал верхний бортовой компьютер.
  - Разработать панель с минималистичным дизайном и компактным экраном (Nextion), где скорость, время и дистанция всегда видны, а сверху при желании добавить или планшет или монитор

## Считывание и парсинг данных UART
Для интеграции с беговой дорожкой необходимо подключиться к UART и декодировать данные (например, скорость `[SETSPD:010]`, наклон `[SETINC:000]`). Подробная инструкция по подключению, считыванию сырых данных и их декодированию находится в [UART_PARSING.md](UART_PARSING.ru.md).

## Преимущества
- **Гибкость**: Совместимость с любыми дорожками, поддерживающими UART.
- **Современность**: Полная замена бортового компьютера на базе ESP32-S3.
- **Прямая связь**: FTMS через BLE без мостов и сторонних приложений.
- **Доступность**: Минимальные затраты на оборудование.

## Рекомендуемое оборудование
  <details>
  <summary><b>ESP32-S3</b>: Настоятельно рекомендуется для высокой производительности и поддержки BLE. (▶️ Нажмите для деталей)</summary>
  ESP32-S Скриншот
  </details>
  
  <details>
  <summary><b>LM2596S</b>: Преобразователь напряжения с 12В на 5В (неизолированный). (▶️ Нажмите для деталей)</summary>
  LM2596S Скриншот
  </details>
  
  <details>
  <summary><b>2-канальный преобразователь уровня</b>: Для согласования 5В (PSA(xx)) и 3.3В (ESP32 S3). (▶️ Нажмите для деталей)</summary>
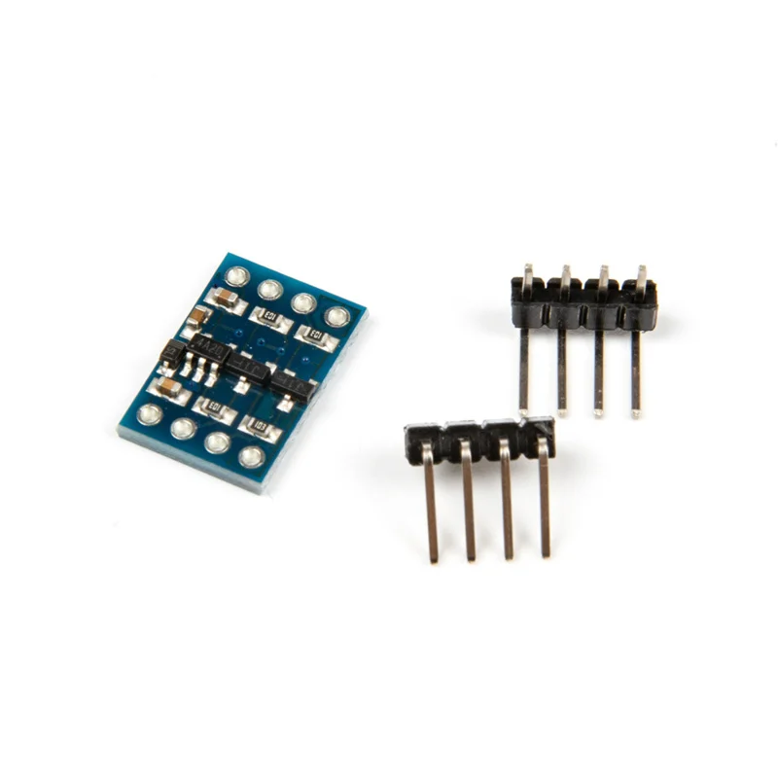
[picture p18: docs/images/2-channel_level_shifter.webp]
  
  </details>
    
  <details>
  <summary><b>Дисплей Nextion</b>: Для улучшенного пользовательского интерфейса и взаимодействия. (▶️ Нажмите для деталей)</summary>
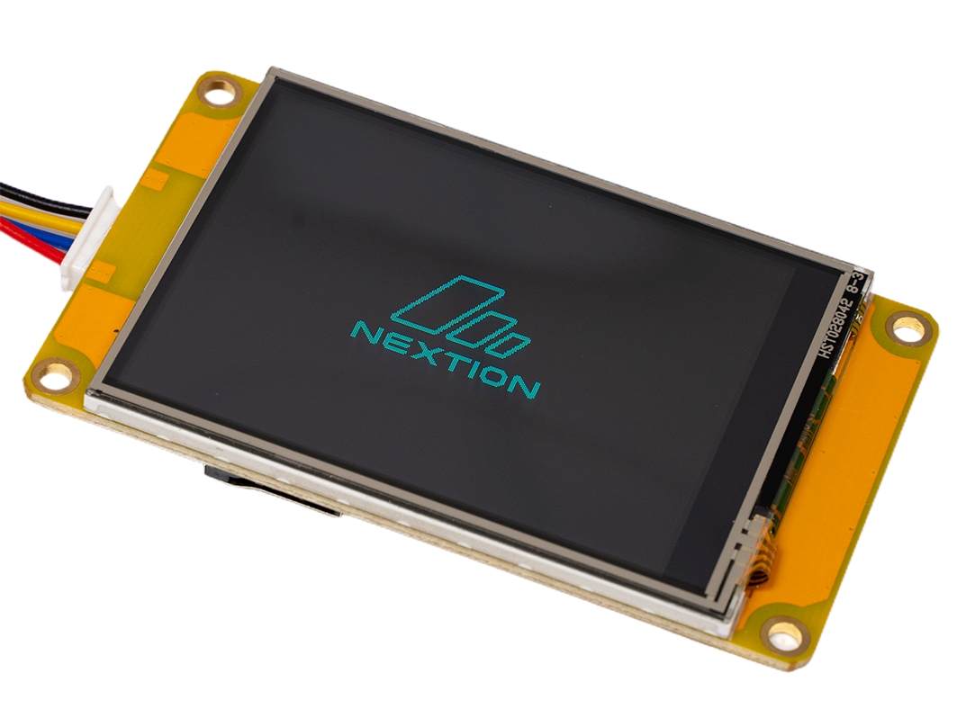
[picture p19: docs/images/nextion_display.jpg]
Скриншот дисплея
  
  </details>
  
  <details>
  <summary><b>FC33</b>: Оптический датчик скорости для калибровки дорожки (опционально). (▶️ Нажмите для деталей)</summary>
  Скриншот оптического датчика скорости
  </details>
  
  <details>
  <summary><b>Беговая дорожка</b>: В идеале с платой PSA(xx), но подойдёт любая модель с поддержкой UART (RX-TX). (▶️ Нажмите для деталей)</summary>
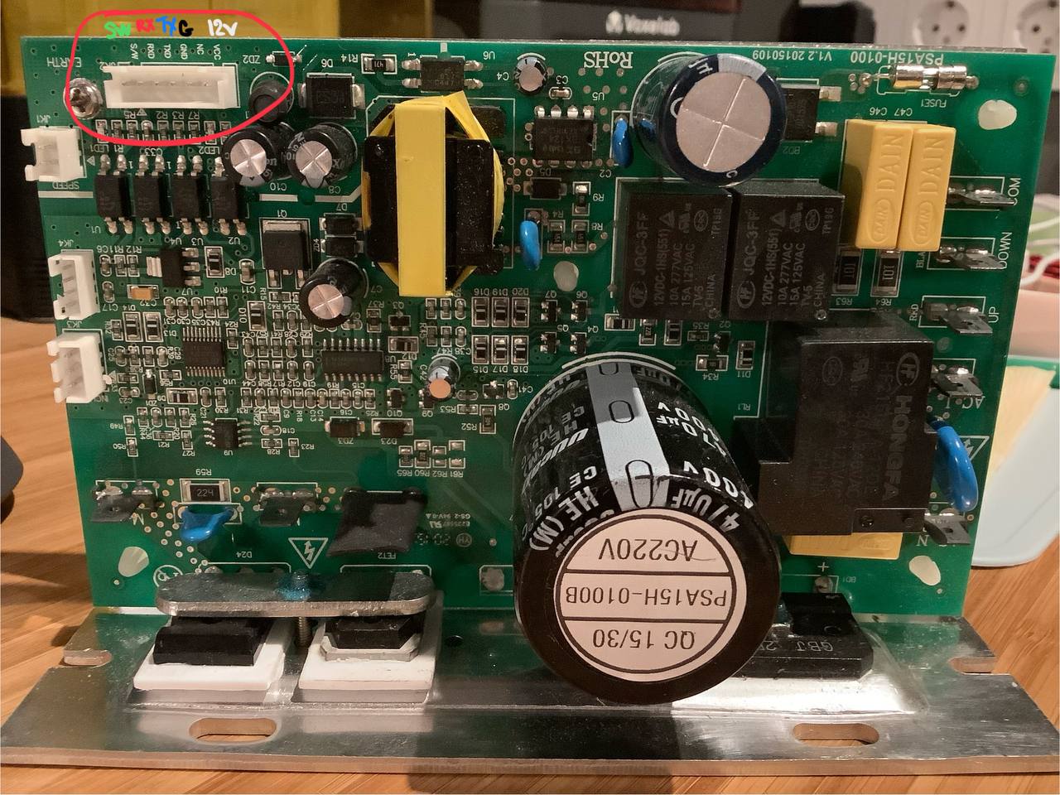
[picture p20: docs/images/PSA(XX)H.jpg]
Скриншот платы PSA(xx)
  
  </details>

## Подключение
<details>
<summary>▶️ Нажмите для деталей подключения</summary>

- ESP32-S3:
  - GPIO17 (TX): Передаёт данные на RX (пин 5) платы PSA(xx) через преобразователь уровня.
  - GPIO18 (RX): Принимает данные от TX (пин 4) платы PSA(xx) через преобразователь уровня.
  - GND: Общий заземлитель с преобразователем уровня (сторона 3.3В).
  - 3.3В: Источник питания для низковольтной (LV) стороны преобразователя уровня.
- ESP32-S3 (подключение питания):
  - LV (низкое напряжение): Сторона 3.3В подключена к ESP32.
  - HV (высокое напряжение): Сторона 5В подключена к PSA(xx).
  - GND (LV): Заземление от ESP32.
  - Vcc (LV): 3.3В от ESP32.
  - GND (HV): Заземление от LM2596S.
  - Vcc (HV): 5В от LM2596S.
- Плата PSA(xx) (6-пиновый разъём):
  - Пин 1 (12В): Подаёт питание на плату, питает вход LM2596S и подключается к пину 6 (SW).
  - Пин 2: Не подключён (не используется).
  - Пин 3 (GND): Общий заземлитель с LM2596S и преобразователем уровня.
  - Пин 4 (TX): Передаёт данные на GPIO18 (RX) ESP32 через преобразователь уровня.
  - Пин 5 (RX): Принимает данные от GPIO17 (TX) ESP32 через преобразователь уровня.
  - Пин 6 (SW): Подключён к пину 1 (12В) для включения дорожки.
- Плата PSA(xx) (дополнительная 6-пиновая секция):
  - Вход 12В: Получает питание от пина 1 (12В) платы PSA(xx).
  - Выход 5В: Подаёт питание на сторону Vcc (HV) преобразователя уровня.
  - GND: Общий заземлитель с PSA(xx) и преобразователем уровня.
- Дисплей Nextion:
  - TX: Передаёт данные на RX (GPIO43) ESP32-S3.
  - RX: Принимает данные от TX (GPIO44) ESP32-S3.
  - GND: Заземление от LM2596S.
  - Vcc: 5В от LM2596S.

</details>

## Функции
### Основные функции
- <details>
  <summary><b>Поддержка Zwift</b>: Полная интеграция с популярной платформой. (▶️ Нажмите для деталей)</summary>
  Скриншот беговой дорожки с Zwift
  </details>
- **Поддержка FTMS**: Совместимость с Kinomap, FitShow и Kinni.
- **Пульсометр**: Подключается через BLE с расчётом зон на основе возраста и пола.
- **Реальные данные**: Точные проценты наклона и калибровка скорости.
- **Управление кнопками**: Регулировка скорости и наклона через GPIO с обратной связью.
- **Ручной режим**: Тренировка без пульсометра.
- **Локальное хранение**: Сохранение тренировок и их визуализация в Grafana.
- **Интерфейс**:
  <details>
  <summary><b>Дисплей Nextion</b>: Поддерживает сенсорный дисплей для удобного мониторинга тренировок и управления дорожкой. (▶️ Нажмите для деталей)</summary>
  Скриншот дисплея Nextion
  </details>
  <details>
  <summary><b>Интерфейс Hassio</b> (▶️ Нажмите для деталей)</summary>
  Скриншот интерфейса Hassio
  </details>

## Пример результатов тренировки
- После завершения тренировки результаты записываются в лог в формате "Workout Summary". Пример:
```yaml
  ===== Workout Summary =====
  User: Gender=Male, Age=41 years, Weight=75.0 kg, Max HR=181 bpm
  Duration: 33.87 min (2032 sec)
  Distance: 3.42 km
  Calories: 178 kcal
  Fat Burned: 9.6 g
  Avg Speed: 6.06 km/h
  Avg Incline: 1.85% (Real Incline: 0.62%)
  Avg MET: 4.21
  Avg VO2: 14.7 ml/kg/min
  Avg Heart Rate: 121 bpm
  Max Heart Rate: 138 bpm
  Heart Rate Zones: Zone1=1:57, Zone2=12:23, Zone3=17:12, Zone4=0:00, Zone5=0:00
  ===== End of Summary =====
```

### Интеллектуальная регулировка
- **Поддержание пульса**: скорость меняется плавно в зависимости от разницы с целевой зоной:
  - Разница > 10 уд/мин: ±0.5 км/ч с шагом 0.1 каждые 2 секунды.
  - Разница < 10 уд/мин: ±0.1 км/ч каждые 20 секунд.

### Разминка
- **Плавный старт**: Скорость увеличивается на 0.1 км/ч каждые 10 секунд в течение заданного периода разминки. Если пульс не достигает Зоны 1 за установленное время, в статусе отображается сообщение, например: «Ожидание пульса 91».
- **Динамическое ускорение**: Если пульс остаётся ниже Зоны 1, через 10 секунд скорость увеличивается на 0.5 км/ч с плавным нарастанием, ждет 10 секунд при необходимости повторяет увеличение на 0.5 км/ч.
- **Переход к основной программе**: Разминка завершается, как только пульс достигает Зоны 1, с плавным переходом к основной программе тренировки.

### Заминка
- **Плавное снижение**: уменьшает скорость, пока пульс не вернётся в зону 1.
- **Настраиваемое время**: работает по аналогии с разминкой.

### Тренировочные программы на основе пульса
- **Пользовательская зона**: Поддерживает заданную зону пульса через регулировку скорости.
- **Сжигание жира**: Зона 2 с плавным управлением скоростью и наклоном.
- **Интервалы**: Чередование Зон 1 и 4 на основе пульса с автоматической настройкой скорости.
- **Восстановление**: Поддержание Зоны 1 для лёгкого бега.
  
## Настройка ESPHome
Файл (config.yaml) настраивает ESP32 S3 для управления беговой дорожкой и подключения пульсометра.
- Конфигурация UART для связи с беговой дорожкой (используется для отправки и получения команд)
```yaml
uart:
  tx_pin: GPIO17    # Передача данных (TX) на GPIO17
  rx_pin: GPIO18    # Приём данных (RX) на GPIO18

# Настройка Bluetooth Low Energy (BLE) для подключения пульсометра
ble_client:
  - mac_address: "XX:XX:XX:XX:XX:XX"  # Замените на MAC-адрес вашего пульсометра
```
## Планы развития
- :white_check_mark:Расширение поддержки FTMS для совместимости Kinomap на iOS
- Добавить Программу фитнес тестирования
- Добавление интерактивных карт высот и новых тренировочных программ.
- :white_check_mark:Разработка дисплея с удобным интерфейсом.
- Поддержка автоматического наклона в Zwift.
- Создание универсальной платы для упрощённой сборки.
- Разработка компонента ESPHome для бесшовной интеграции в экосистему.
- Интеграция датчика расстояния (TOF400C-VL53L1X) для управления скоростью без кнопок.
- Передача данных через MQTT для интеграции вне Home Assistant.
- Создание веб-интерфейса для управления без Home Assistant.

## История изменений
Для подробной истории изменений см. [CHANGELOG.md](/CHANGELOG.md).

## Авторы
Создано [@samsonovss](https://t.me/samsonovss) & xAI Assistant

### **Поддержите проект**  
Если вы хотите поддержать проект и помочь его развитию, угостите меня кофе! Ваши пожертвования помогают улучшать проект:
- **PayPal**: samsonov@hotmail.com
- **BTC:** `bc1q3cza0kasutzes4hfddxuclmd9ghn5v7zw2nr5c`  
- **USDT (TRC-20):** `0x5dd5a346Dd64dfE938a60D7b24b633b1ACE01719`
  
Любая поддержка важна — спасибо!

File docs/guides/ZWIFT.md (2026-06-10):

# Zwift Connection and Automatic Incline

[Русская версия](ZWIFT.ru.md) | [Back to README](../../README.md)

This guide describes the native Zwift connection and the conversion of real route grade into a treadmill-specific incline level.

## What Zwift Sends

Zwift uses real route grade:

- `3%` means a 3 m rise over 100 m of travel;
- `0%` means flat terrain;
- a negative value means downhill.

Incline levels on many consumer treadmills do not equal real percentages. For example, a maximum level of `15` may physically produce only about a `5%` grade.

## Pairing

1. Turn on the treadmill and wait for ESPHome to start.
2. Open the Zwift device-pairing screen.
3. Select `KICKR RUN` as the running-speed source.
4. Select the same device under controllable incline when Zwift offers that option.
5. Confirm that the BLE status in Home Assistant changes to connected.
6. Verify that `Zwift Requested Incline` changes while moving along the route.

Zwift may use separate BLE connections for speed and the controllable device. The configuration allows two BLE server clients.

## Home Assistant Settings

### Zwift Auto Incline

Allows the mapped value to control the physical incline mechanism.

When disabled:

- Zwift commands are still received;
- diagnostic sensors continue to update;
- the physical incline does not change.

Keep it disabled during initial pairing and calibration.

### Treadmill Maximum Incline Level

The maximum value accepted by the treadmill controller. The current implementation supports `1-15`.

### Treadmill Real Grade At Maximum

The measured physical belt grade at the treadmill's maximum incline level.

### Zwift Incline Intensity

Effect scaling:

- `100%` uses the full calculated value;
- `50%` uses half;
- `0%` always produces zero incline.

### Diagnostic Sensors

- `Zwift Requested Incline` is the original Zwift grade;
- `Zwift Mapped Treadmill Incline` is the calculated treadmill target.

## Measuring Real Grade

1. Stop the belt.
2. Set the treadmill to its maximum incline level.
3. Measure the vertical belt rise relative to the flat position.
4. Measure the horizontal length used for the measurement.
5. Calculate:

```text
grade, % = rise / horizontal length * 100
```

Example:

```text
rise = 6 cm
length = 120 cm
real grade = 6 / 120 * 100 = 5%
```

Use:

```text
Treadmill Maximum Incline Level = 15
Treadmill Real Grade At Maximum = 5
```

## Mapping Formula

```text
treadmill level =
    Zwift grade
    * treadmill maximum level
    / real grade at maximum
    * intensity / 100
```

Example with maximum level `15`, real maximum grade `5%`, and intensity `100%`:

| Zwift grade | Treadmill level |
|---:|---:|
| -3% | 0 |
| 1% | 3 |
| 2% | 6 |
| 3% | 9 |
| 5% | 15 |
| 8% | 15, limited |

Negative values are mapped to `0` because a typical treadmill cannot lower its front below the flat position.

## Safe Validation

1. Disable `Zwift Auto Incline`.
2. Start a route and verify `Zwift Requested Incline`.
3. Compare it with `Zwift Mapped Treadmill Incline`.
4. Set a low intensity such as `20%`.
5. Step off the belt and enable automatic incline.
6. Verify mechanism direction and travel limits.
7. Increase intensity gradually.

Do not enable native automatic incline until direction and hardware limits have been verified.

## Recommended Documentation Media

Three screenshots are sufficient for the README:

1. `KICKR RUN` on the Zwift pairing screen;
2. the controllable-incline selection;
3. the Home Assistant card with settings and diagnostic sensors.

A short video should show the Zwift grade, diagnostic sensors, and physical incline changing together. Use a small preview linked to the video instead of committing another large MOV file to Git.

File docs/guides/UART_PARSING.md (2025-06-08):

# Guide to Reading and Decoding UART Data for a Treadmill

## Step 1: Connecting to the Upper Control Board
- **Photo**: Image of the upper control board of the treadmill.  
  The UART connector (usually 6-pin, with RX and TX) is circled in the photo.  
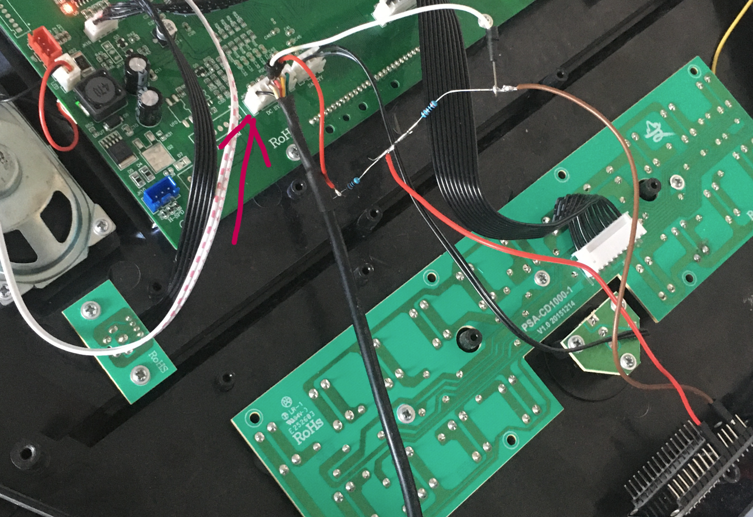
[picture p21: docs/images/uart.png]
[photo of control board]
  
- **Key Connection Notes**:  
  - The upper board ("control board") sends commands to the lower board approximately every half second.  
  - The lower board only sends confirmations as feedback and does not initiate data itself.  
  - To read commands, connect specifically to the upper board!
- **Connection**:  
  - Use an ESP32-S3 to connect to the treadmill's board.  
  - **GPIO17 (TX)**: Connect to RX (e.g., Pin 5 on the connector) via a level shifter (5V → 3.3V).  
  - **GPIO18 (RX)**: Connect to TX (e.g., Pin 4 on the connector) via a level shifter.  
  - **GND**: Common ground with the level shifter and the board.  
  - **Power**: Use an LM2596S to convert 12V to 5V, then supply 3.3V to the ESP32-S3.

## Step 2: Reading Raw UART Data
- **Goal**: Capture raw data sent by the control board, encoded in ASCII.
- **UART Setup**:  
  - Start with a basic ESPHome configuration to capture all messages without noise filtering.  
  - Use the following code to output raw data:
  ```yaml
  uart:
    - id: uart_bus
      tx_pin: 
        number: GPIO17
        inverted: false
      rx_pin: 
        number: GPIO18
        mode: 
          input: true
          pullup: true
        inverted: false
      baud_rate: 5000
      data_bits: 8
      parity: NONE
      stop_bits: 1
      rx_buffer_size: 1024
      debug:
        direction: RX
        dummy_receiver: false
        after:
          timeout: 100ms
          bytes: 30
        sequence:
          - lambda: |-
              std::vector<uint8_t> filtered_bytes;
              for (auto byte : bytes) {
                if (byte != 0x00) {
                  filtered_bytes.push_back(byte);
                }
              }
              if (!filtered_bytes.empty()) {
                UARTDebug::log_string(direction, filtered_bytes);
              }
  ```

- **Selecting UART Baud Rate**:  
  - The baud rate is unknown and needs to be determined.  
  - Add a slider to the ESPHome configuration to adjust the speed, step 100: (in my case, the speed was 4800 - 5000)
  ```yaml
  number:
    - platform: template
      name: "UART Baud Rate"
      id: uart_baud_rate
      min_value: 1000
      max_value: 115200
      step: 100
      initial_value: 5000
      optimistic: true
      restore_value: yes
      entity_category: config
      icon: "mdi:swap-horizontal"
      on_value:
        - lambda: |-
            id(uart_bus).flush();
            uint32_t new_baud_rate = (uint32_t)x;
            ESP_LOGD("UART", "Changing baud rate from %i to %i", id(uart_bus).get_baud_rate(), new_baud_rate);
            if (id(uart_bus).get_baud_rate() != new_baud_rate) {
              id(uart_bus).set_baud_rate(new_baud_rate);
              id(uart_bus).load_settings();
            }
  ```
- **Logging in Debug Mode**:
  ```yaml
  logger:
    level: DEBUG
  ```

- **Process**:  
  - Adjust the slider, changing the speed (e.g., from 1000 to 115200 with a step of 100).  
  - Monitor the logs in ESPHome (via `logger`).  
  - If raw ASCII commands start appearing, the connection and baud rate are correct.  
  - Note this speed (in my case, for example, 4900 or 5000).

## Step 3: Decoding Data from ASCII to Text
- **Raw Data**: From the previous step, you obtained byte streams, possibly with noise (0x00). These are encoded in ASCII, where each byte represents a character (e.g., 0x5B = `[`, 0x30 = `0`).
- **How to Decode in Real Life**:  
  - **View Bytes**: In the logs, you’ll see hex values, e.g., `5B 53 45 54 53 50 44 3A 30 31 30 5D`.  
  - **Decoding with Converters**:  
    - Use online tools like a "Hex to ASCII" converter.  
    - Input the hex string (e.g., `5B 53 45 54 53 50 44 3A 30 31 30 5D`).  
    - Result: text, e.g., `[SETSPD:010]`, where the command indicates a speed of 1.0 km/h.  
  - **Manual Decoding**:  
    - Find an ASCII table (e.g., on ascii-code.com).  
    - Convert each hex byte to a character:  
      - `5B` → 91 → `[`  
      - `53` → 83 → `S`  
      - `45` → 69 → `E`  
      - `54` → 84 → `T`  
      - `53` → 83 → `S`  
      - `50` → 80 → `P`  
      - `44` → 68 → `D`  
      - `3A` → 58 → `:`  
      - `30` → 48 → `0`  
      - `31` → 49 → `1`  
      - `30` → 48 → `0`  
      - `5D` → 93 → `]`  
    - Result: `5B 53 45 54 53 50 44 3A 30 31 30 5D` → `[SETSPD:010]`.  
  - **Interpretation**: The command `[SETSPD:010]` means a speed of 1.0 km/h, `[SETINC:000]` means an incline of 0%. Ignore noise (0x00).  
- **Filtering and Decoding in Code**:  
  - Remove noise (0x00) and convert to readable form.  
  - This code parses commands like `[SETSPD:010]` and `[SETINC:000]`. If your command names differ, replace them with your own:
  ```yaml
  uart:
    - id: uart_bus
      tx_pin: 
        number: GPIO17
        inverted: false
      rx_pin: 
        number: GPIO18
        mode: 
          input: true
          pullup: true
        inverted: false
      baud_rate: 4900
      data_bits: 8
      parity: NONE
      stop_bits: 1
      rx_buffer_size: 512
      debug:
        direction: RX
        dummy_receiver: false
        after:
          timeout: 100ms
          bytes: 30
        sequence:
          - lambda: |-
              char message[31] = {0};
              int len = 0;
              for (size_t i = 0; i < std::min(bytes.size(), size_t(30)); i++) {
                if (bytes[i] != 0x00) {
                  message[len++] = bytes[i];
                }
              }
              if (len > 0) {
                ESP_LOGD("UART", "Received: %s", message);
                auto parse_command = [&](const char* start) {
                  if (start == nullptr || *start != '[') return;
                  const char* end = strchr(start, ']');
                  if (end == nullptr || end <= start + 1) return;
                  const char* colon = strchr(start + 1, ':');
                  if (colon == nullptr || colon >= end) return;
                  char command_name[16] = {0};
                  char command_value[16] = {0};
                  int name_len = colon - (start + 1);
                  int value_len = end - (colon + 1);
                  if (name_len >= sizeof(command_name) || value_len >= sizeof(command_value)) {
                    ESP_LOGW("UART", "Command or value too long: %s", start);
                    return;
                  }
                  memcpy(command_name, start + 1, name_len);
                  memcpy(command_value, colon + 1, value_len);
                  ESP_LOGD("UART", "Command: %s, Value: %s", command_name, command_value);
                  if (strcmp(command_name, "SETSPD") == 0) {
                    int speed = 0;
                    bool valid = true;
                    for (int i = 0; command_value[i] != '\0' && i < 5; i++) {
                      if (command_value[i] < '0' || command_value[i] > '9') {
                        valid = false;
                        break;
                      }
                      speed = speed * 10 + (command_value[i] - '0');
                    }
                    if (valid) {
                      id(treadmill_speed_feedback) = speed;
                      ESP_LOGD("UART", "Speed updated: %d", speed);
                    } else {
                      ESP_LOGW("UART", "Invalid speed: %s", command_value);
                    }
                  }
                  else if (strcmp(command_name, "SETINC") == 0) {
                    int incline = 0;
                    bool valid = true;
                    for (int i = 0; command_value[i] != '\0' && i < 5; i++) {
                      if (command_value[i] < '0' || command_value[i] > '9') {
                        valid = false;
                        break;
                      }
                      incline = incline * 10 + (command_value[i] - '0');
                    }
                    if (valid) {
                      id(treadmill_incline_feedback) = incline;
                      ESP_LOGD("UART", "Incline updated: %d", incline);
                    } else {
                      ESP_LOGW("UART", "Invalid incline: %s", command_value);
                    }
                  }
                  else {
                    ESP_LOGD("UART", "Unknown command processed: %s=%s", command_name, command_value);
                  }
                };
                const char* start = strchr(message, '[');
                parse_command(start);
                if (start == nullptr) {
                  ESP_LOGD("UART", "No commands found in format [COMMAND:VALUE]: %s", message);
                }
              }
  ```
- **Result**:  
  - Raw data is filtered, and commands like `[SETSPD:010]` (speed 1 km/h) or `[SETINC:000]` (incline 0%) are decoded.  
  - Feedback values are stored in variables, e.g., `treadmill_speed_feedback` and `treadmill_incline_feedback`, for further use.

## Summary
- Connect to UART as shown in the photo and read raw data, adjusting the baud rate with the slider.  
- When raw ASCII data starts coming in:  
- Decode the data from ASCII using tools like a converter or manually (with an ASCII table), filtering noise and extracting commands to obtain readable speed and incline values.  
- This is my method for decoding UART for a treadmill!

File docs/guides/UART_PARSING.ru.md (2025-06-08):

# Инструкция по считыванию и декодированию данных UART для беговой дорожки

## Шаг 1: Подключение к верхнему бортовому компьютеру
- **Фотография**: Изображение верхнего бортового компьютера беговой дорожки.
  Разъем UART (обычно 6-контактный, с RX и TX) обведен на фото.
  
  [фото бортового компьютера
- **Важно о подключении**:  
  - Верхняя плата ("бортовой компьютер") отправляет команды нижней плате с интервалом примерно в полсекунды.
  - Нижняя плата подтверждает получение, и отправляет только ответ в виде обратной связи.
  - Для считывания команд подключайтесь именно к верхней плате!
- **Подключение**:  
  - Используйте ESP32-S3 для подключения к плате беговой дорожки.  
  - **GPIO17 (TX)**: Подключите к RX (например, на разъеме Pin 5) на плате через преобразователь уровня (5В → 3.3В).  
  - **GPIO18 (RX)**: Подключите к TX (например, на разъеме Pin 4) на плате через преобразователь уровня.  
  - **GND**: Общий провод с преобразователем уровня и платой.  
  - **Питание**: Используйте LM2596S для преобразования 12В в 5В, затем подключите 3.3В к ESP32-S3.

## Шаг 2: Считывание сырых данных UART
- **Цель**: Получить сырые данные, отправляемые бортовым компьютером, они закодированы в ASCII.
- **Настройка UART**:  
  - Начните с базовой конфигурации в ESPHome для захвата всех сообщений без фильтрации шума.  
  - Используйте следующий код для вывода сырых данных:
  ```yaml
  uart:
    - id: uart_bus
      tx_pin: 
        number: GPIO17
        inverted: false
      rx_pin: 
        number: GPIO18
        mode: 
          input: true
          pullup: true
        inverted: false
      baud_rate: 5000
      data_bits: 8
      parity: NONE
      stop_bits: 1
      rx_buffer_size: 1024
      debug:
        direction: RX
        dummy_receiver: false
        after:
          timeout: 100ms
          bytes: 30
        sequence:
          - lambda: |-
              std::vector<uint8_t> filtered_bytes;
              for (auto byte : bytes) {
                if (byte != 0x00) {
                  filtered_bytes.push_back(byte);
                }
              }
              if (!filtered_bytes.empty()) {
                UARTDebug::log_string(direction, filtered_bytes);
              }
  ```

- **Подбор скорости UART (Baud Rate)**:  
  - Скорость передачи (baud rate) неизвестна, поэтому ее нужно определить.  
  - Добавьте в конфигурацию ESPHome слайдер для подбора скорости, шаг 100: (в моем случае скорость 4800 - 5000)
  ```yaml
  number:
    - platform: template
      name: "UART Baud Rate"
      id: uart_baud_rate
      min_value: 1000
      max_value: 115200
      step: 100
      initial_value: 5000
      optimistic: true
      restore_value: yes
      entity_category: config
      icon: "mdi:swap-horizontal"
      on_value:
        - lambda: |-
            id(uart_bus).flush();
            uint32_t new_baud_rate = (uint32_t)x;
            ESP_LOGD("UART", "Changing baud rate from %i to %i", id(uart_bus).get_baud_rate(), new_baud_rate);
            if (id(uart_bus).get_baud_rate() != new_baud_rate) {
              id(uart_bus).set_baud_rate(new_baud_rate);
              id(uart_bus).load_settings();
            }
  ```
- **лог в режиме (Debug)**:
  ```yaml
  logger:
    level: DEBUG
  ```

- **Процесс**:  
  - Двигайте слайдер, изменяя скорость (например, от 1000 до 115200 с шагом 100).  
  - Наблюдайте за логами в ESPHome (через `logger`).  
  - Если начинают поступать сырые команды в ASCII значит подключение и подбор скорость коректны.  
  - Запомните эту скорость (в моем случае, например, 4900 или 5000).

## Шаг 3: Декодирование данных из ASCII в текст
- **Сырые данные**: На предыдущем шаге вы получили потоки байтов, возможно, с шумом (0x00). Эти данные закодированы в ASCII, где каждый байт представляет символ (например, 0x5B = `[`, 0x30 = `0`).
- **Как декодировать в реальной жизни**:  
  - **Просмотр байтов**: В логах вы увидите hex-значения, например, `5B 53 45 54 53 50 44 3A 30 31 30 5D`.  
  - **Декодирование с помощью конвертеров**:  
    - Используйте онлайн-инструменты, такие как "Hex to ASCII" конвертер.  
    - Вставьте hex-строку (например, `5B 53 45 54 53 50 44 3A 30 31 30 5D`).  
    - Результат: текст, например, `[SETSPD:010]`, где команда означает скорость 1.0 км/ч.  
  - **Ручное декодирование**:  
    - Найдите таблицу ASCII (например, на ascii-code.com).  
    - Преобразуйте каждый hex-байт в символ:  
      - `5B` → 91 → `[`  
      - `53` → 83 → `S`  
      - `45` → 69 → `E`  
      - `54` → 84 → `T`  
      - `53` → 83 → `S`  
      - `50` → 80 → `P`  
      - `44` → 68 → `D`  
      - `3A` → 58 → `:`  
      - `30` → 48 → `0`  
      - `31` → 49 → `1`  
      - `30` → 48 → `0`  
      - `5D` → 93 → `]`  
    - Итог: `5B 53 45 54 53 50 44 3A 30 31 30 5D` → `[SETSPD:010]`.  
  - **Интерпретация**: Команда `[SETSPD:010]` — это скорость 1.0 км/ч, `[SETINC:000]` — наклон 0%. Игнорируйте шум (0x00).  
- **Фильтрация и декодирование в коде**:  
  - Очистите данные от шума (0x00) и преобразуйте в читаемый вид.  
  - Данный код использует парсинг команд `[SETSPD:010]` и `[SETINC:000]` , если ваше название команд отличается замените на свои: 
  ```yaml
  uart:
    - id: uart_bus
      tx_pin: 
        number: GPIO17
        inverted: false
      rx_pin: 
        number: GPIO18
        mode: 
          input: true
          pullup: true
        inverted: false
      baud_rate: 4900
      data_bits: 8
      parity: NONE
      stop_bits: 1
      rx_buffer_size: 512
      debug:
        direction: RX
        dummy_receiver: false
        after:
          timeout: 100ms
          bytes: 30
        sequence:
          - lambda: |-
              char message[31] = {0};
              int len = 0;
              for (size_t i = 0; i < std::min(bytes.size(), size_t(30)); i++) {
                if (bytes[i] != 0x00) {
                  message[len++] = bytes[i];
                }
              }
              if (len > 0) {
                ESP_LOGD("UART", "Получено: %s", message);
                auto parse_command = [&](const char* start) {
                  if (start == nullptr || *start != '[') return;
                  const char* end = strchr(start, ']');
                  if (end == nullptr || end <= start + 1) return;
                  const char* colon = strchr(start + 1, ':');
                  if (colon == nullptr || colon >= end) return;
                  char command_name[16] = {0};
                  char command_value[16] = {0};
                  int name_len = colon - (start + 1);
                  int value_len = end - (colon + 1);
                  if (name_len >= sizeof(command_name) || value_len >= sizeof(command_value)) {
                    ESP_LOGW("UART", "Слишком длинная команда или значение: %s", start);
                    return;
                  }
                  memcpy(command_name, start + 1, name_len);
                  memcpy(command_value, colon + 1, value_len);
                  ESP_LOGD("UART", "Команда: %s, Значение: %s", command_name, command_value);
                  if (strcmp(command_name, "SETSPD") == 0) {
                    int speed = 0;
                    bool valid = true;
                    for (int i = 0; command_value[i] != '\0' && i < 5; i++) {
                      if (command_value[i] < '0' || command_value[i] > '9') {
                        valid = false;
                        break;
                      }
                      speed = speed * 10 + (command_value[i] - '0');
                    }
                    if (valid) {
                      id(treadmill_speed_feedback) = speed;
                      ESP_LOGD("UART", "Скорость обновлена: %d", speed);
                    } else {
                      ESP_LOGW("UART", "Некорректная скорость: %s", command_value);
                    }
                  }
                  else if (strcmp(command_name, "SETINC") == 0) {
                    int incline = 0;
                    bool valid = true;
                    for (int i = 0; command_value[i] != '\0' && i < 5; i++) {
                      if (command_value[i] < '0' || command_value[i] > '9') {
                        valid = false;
                        break;
                      }
                      incline = incline * 10 + (command_value[i] - '0');
                    }
                    if (valid) {
                      id(treadmill_incline_feedback) = incline;
                      ESP_LOGD("UART", "Наклон обновлен: %d", incline);
                    } else {
                      ESP_LOGW("UART", "Некорректный наклон: %s", command_value);
                    }
                  }
                  else {
                    ESP_LOGD("UART", "Неизвестная команда обработана: %s=%s", command_name, command_value);
                  }
                };
                const char* start = strchr(message, '[');
                parse_command(start);
                if (start == nullptr) {
                  ESP_LOGD("UART", "Не найдено команд в формате [КОМАНДА:ЗНАЧЕНИЕ]: %s", message);
                }
              }
  ```
- **Результат**:  
  - Сырые данные фильтруются, и команды вроде `[SETSPD:010]` (скорость 1 км/ч) или `[SETINC:000]` (наклон 0%) декодируются.  
  - Значения обратной связи сохраняются в переменные, например, `treadmill_speed_feedback` и `treadmill_incline_feedback`, для дальнейшего использования.

## Итог
- Подключитесь к UART, как показано на фото, и считайте сырые данные, подбирая скорость (baud rate) с помощью слайдера.  
- Когда данные начнут поступать в сыром виде ASCII
- Декодируйте данные из ASCII через помощью инструментов - конвертера или вручную (с таблицей ASCII), фильтруя шум и извлекая команды для получения читаемых значений скорости и наклона.  
- Это мой метод дешифровки UART для беговой дорожки

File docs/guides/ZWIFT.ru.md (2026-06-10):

# Zwift: подключение и автоматический наклон

[English version](ZWIFT.md) | [Вернуться к README](../../README.ru.md)

Это руководство описывает нативное подключение дорожки к Zwift и преобразование реального градиента трассы в уровень наклона конкретной дорожки.

## Что передаёт Zwift

Zwift использует реальный градиент трассы:

- `3%` означает подъём на 3 м на каждые 100 м пути;
- `0%` означает ровный участок;
- отрицательное значение означает спуск.

Уровни наклона многих бытовых дорожек не совпадают с реальными процентами. Например, максимальный уровень `15` может физически давать только около `5%`.

## Подключение

1. Включите дорожку и дождитесь запуска ESPHome.
2. Откройте экран сопряжения устройств Zwift.
3. Выберите `KICKR RUN` как источник скорости бега.
4. Выберите то же устройство в разделе управляемого наклона, если Zwift показывает этот пункт.
5. Убедитесь, что в Home Assistant статус BLE изменился на подключённый.
6. Проверьте изменение сенсора `Zwift Requested Incline` во время движения по трассе.

Zwift может использовать отдельные BLE-соединения для скорости и управляемого устройства. Конфигурация допускает два клиента BLE-сервера.

## Настройки Home Assistant

### Zwift Auto Incline

Разрешает передавать рассчитанный уровень физическому механизму наклона.

При выключении:

- команды Zwift продолжают приниматься;
- диагностические сенсоры продолжают обновляться;
- физический наклон не изменяется.

Первое подключение и калибровку выполняйте с выключенной автоматикой.

### Treadmill Maximum Incline Level

Максимальное значение, принимаемое контроллером дорожки. Для текущей реализации допустим диапазон `1-15`.

### Treadmill Real Grade At Maximum

Фактический уклон полотна в процентах при максимальном уровне дорожки.

### Zwift Incline Intensity

Масштаб эффекта:

- `100%` — полное рассчитанное значение;
- `50%` — половина;
- `0%` — наклон всегда равен нулю.

### Диагностические сенсоры

- `Zwift Requested Incline` — исходный градиент Zwift;
- `Zwift Mapped Treadmill Incline` — рассчитанный уровень дорожки.

## Измерение реального уклона

1. Остановите полотно.
2. Установите максимальный уровень наклона.
3. Измерьте вертикальный подъём полотна относительно горизонтального положения.
4. Измерьте горизонтальную длину участка, на котором выполнялось измерение.
5. Рассчитайте:

```text
уклон, % = подъём / горизонтальная длина * 100
```

Пример:

```text
подъём = 6 см
длина = 120 см
реальный уклон = 6 / 120 * 100 = 5%
```

В этом случае:

```text
Treadmill Maximum Incline Level = 15
Treadmill Real Grade At Maximum = 5
```

## Формула преобразования

```text
уровень дорожки =
    градиент Zwift
    * максимальный уровень дорожки
    / реальный уклон на максимуме
    * интенсивность / 100
```

Пример при максимальном уровне `15`, реальном максимуме `5%` и интенсивности `100%`:

| Градиент Zwift | Уровень дорожки |
|---:|---:|
| -3% | 0 |
| 1% | 3 |
| 2% | 6 |
| 3% | 9 |
| 5% | 15 |
| 8% | 15, ограничение |

Отрицательные значения преобразуются в `0`, поскольку обычная дорожка не умеет опускать переднюю часть ниже горизонтального положения.

## Безопасная проверка

1. Выключите `Zwift Auto Incline`.
2. Запустите маршрут и проверьте `Zwift Requested Incline`.
3. Сравните его с `Zwift Mapped Treadmill Incline`.
4. Установите небольшую интенсивность, например `20%`.
5. Сойдите с полотна и включите автоматический наклон.
6. Проверьте движение механизма и предельные положения.
7. Постепенно увеличивайте интенсивность.

Не включайте нативный автонаклон до проверки правильности направления движения и аппаратных ограничений.

## Рекомендуемые изображения для документации

Для README достаточно трёх изображений:

1. `KICKR RUN` на экране сопряжения Zwift;
2. пункт выбора управляемого наклона;
3. карточка Home Assistant с настройками и диагностическими сенсорами.

Короткое видео должно одновременно показывать изменение градиента Zwift, диагностических сенсоров и физического наклона. Для README лучше использовать небольшое превью со ссылкой на видео, а не хранить крупный MOV-файл в Git.

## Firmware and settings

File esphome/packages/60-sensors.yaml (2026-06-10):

# Сенсоры
sensor:
  # === BEGIN EXPERIMENTAL_KICKR_RUN ===
  # Zwift Requested Incline — исходный реальный градиент трассы, который
  # присылает Zwift через фирменную характеристику KICKR RUN.
  # Значение может быть отрицательным на спуске.
  # Для удаления эксперимента удалить все блоки с меткой EXPERIMENTAL_KICKR_RUN.
  - platform: template
    name: "Zwift Requested Incline"
    id: zwift_requested_incline
    unit_of_measurement: "%"
    accuracy_decimals: 2
    icon: "mdi:slope-uphill"
    update_interval: never

  # Zwift Mapped Treadmill Incline — рассчитанный уровень дорожки после
  # применения калибровки и интенсивности. Это значение показывает, какую
  # цель автоматика установит на дорожке; при выключенной автоматике сенсор
  # продолжает считать и показывать результат, но мотором не управляет.
  - platform: template
    name: "Zwift Mapped Treadmill Incline"
    id: zwift_mapped_incline
    unit_of_measurement: "level"
    accuracy_decimals: 1
    icon: "mdi:angle-acute"
    update_interval: never
  # === END EXPERIMENTAL_KICKR_RUN ===

  - platform: debug
    free:
      name: "Heap Free"            #    - Heap Free — свободная оперативная память (байты).
    block:
      name: "Heap Max Block"       #    - Heap Max Block — максимальный непрерывный блок памяти (байты).
    loop_time:
      name: "Loop Time"            #    - Loop Time — время выполнения основного цикла (мс).
    psram:
      name: "Free PSRAM"           #    - Free PSRAM — свободная внешняя PSRAM (если доступна).
    cpu_frequency:
      name: "CPU Frequency"        #    - CPU Frequency — текущая частота процессора (МГц).

  - platform: template
    name: "Zone1"
    id: last_zone1_time
    unit_of_measurement: s
    device_class: duration
    accuracy_decimals: 0
    icon: mdi:heart-pulse
    lambda: |-
      return id(zone1_time_stored);

  - platform: template
    name: "Zone2"
    id: last_zone2_time
    unit_of_measurement: s
    device_class: duration
    accuracy_decimals: 0
    icon: mdi:heart-pulse
    lambda: |-
      return id(zone2_time_stored);

  - platform: template
    name: "Zone3"
    id: last_zone3_time
    unit_of_measurement: s
    device_class: duration
    accuracy_decimals: 0
    icon: mdi:heart-pulse
    lambda: |-
      return id(zone3_time_stored);

  - platform: template
    name: "Zone4"
    id: last_zone4_time
    unit_of_measurement: s
    device_class: duration
    accuracy_decimals: 0
    icon: mdi:heart-pulse
    lambda: |-
      return id(zone4_time_stored);

  - platform: template
    name: "Zone5"
    id: last_zone5_time
    unit_of_measurement: s
    device_class: duration
    accuracy_decimals: 0
    icon: mdi:heart-pulse
    lambda: |-
      return id(zone5_time_stored);

  # Время тренировки (секунды)
  - platform: template
    name: "Last Time"
    id: last_time
    unit_of_measurement: s
    device_class: duration
    accuracy_decimals: 0
    icon: mdi:timer-outline
    lambda: |-
      return id(last_time_stored);

  # Дистанция
  - platform: template
    name: "Last Distance"
    id: last_distance
    unit_of_measurement: "km"
    accuracy_decimals: 2
    icon: mdi:map-marker-distance
    lambda: |-
      return id(last_distance_stored);

  # Калории
  - platform: template
    name: "Last Calories"
    id: last_calories
    unit_of_measurement: "kcal"
    accuracy_decimals: 0
    icon: mdi:fire
    lambda: |-
      return id(last_calories_stored);

  # Жир
  - platform: template
    name: "Last Fat"
    id: last_fat
    unit_of_measurement: "g"
    accuracy_decimals: 1
    icon: mdi:scale-balance
    lambda: |-
      return id(fat_grams_stored);

  # Средняя скорость
  - platform: template
    name: "Last Avg Speed"
    id: last_avg_speed
    unit_of_measurement: "km/h"
    accuracy_decimals: 1
    icon: mdi:speedometer
    lambda: |-
      return id(avg_speed_stored);

  # Средний наклон
  - platform: template
    name: "Last Avg Incline"
    id: last_avg_incline
    unit_of_measurement: "%"
    accuracy_decimals: 1
    icon: mdi:terrain
    lambda: |-
      return id(avg_incline_stored);

  # Средний пульс
  - platform: template
    name: "Last Avg HR"
    id: last_avg_hr
    unit_of_measurement: "bpm"
    accuracy_decimals: 0
    icon: mdi:heart-pulse
    lambda: |-
      return id(avg_heart_rate_stored);

  # Максимальный пульс
  - platform: template
    name: "Last Max HR"
    id: last_max_hr
    unit_of_measurement: "bpm"
    accuracy_decimals: 0
    icon: mdi:heart-flash
    lambda: |-
      return id(max_heart_rate_stored);

  # VO2
  - platform: template
    name: "Last Avg VO2"
    id: last_vo2
    unit_of_measurement: "ml/kg/min"
    accuracy_decimals: 1
    icon: mdi:lungs
    lambda: |-
      return id(avg_vo2_stored);

  # MET
  - platform: template
    name: "Last Avg MET"
    id: last_met
    unit_of_measurement: "MET"
    accuracy_decimals: 2
    icon: mdi:run
    lambda: |-
      return id(avg_met_stored);
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

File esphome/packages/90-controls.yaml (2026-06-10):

select:
# Профиль разгона дорожки (варианты: Soft / Normal / Fast / Technogym)
  - platform: template
    name: "Acceleration Profile"
    id: accel_profile
    optimistic: true
    options:
      - "Soft"
      - "Normal"
      - "Fast"
      - "Technogym"
    initial_option: "Soft"

# Профиль коррекции скорости (варианты: Soft / Precise / Aggressive)
  - platform: template
    name: "Speed Correction Profile"
    id: speed_corr_profile
    optimistic: true
    options:
      - "Soft"
      - "Precise"
      - "Aggressive"
    initial_option: "Soft"

# Выбор тренировочной программы
# При смене значения автоматически задаются параметры:
#   - время тренировки, разминки и заминки
#   - выбор пульсовой зоны (zone_select)
#   - сброс/инициализация таймеров и флагов (remaining_run_time, manual_stop, interval_phase)
# Таким образом, выбор программы сразу подготавливает дорожку к нужному сценарию.
  - platform: template
    name: "Workout Program"
    id: program_select
    restore_value: no
    options:
      - "None"
      - "Pulse Zone"
      - "Fat Burn"
      - "Recovery run"
      - "HIIT"
    initial_option: "None"
    optimistic: true
    on_value:
      - lambda: |-
          std::string program = x;

          if (program == "None") {
            id(zone_select).publish_state("1");
            id(set_run_time).publish_state(00.0); //время тренировки 
            id(set_warm_up_time).publish_state(00.0); //время разминки
            id(set_cool_down_time).publish_state(00.0); //время заминки
            //id(stop_program).execute();
          } else if (program == "Fat Burn") {
            id(zone_select).publish_state("2");
            id(set_run_time).publish_state(40.0); //время тренировки 
            id(set_warm_up_time).publish_state(03.0); //время разминки
            id(set_cool_down_time).publish_state(03.0); //время заминки
            id(remaining_run_time) = 40 * 60;
            id(manual_stop) = false;
          } else if (program == "Recovery run") {
            id(zone_select).publish_state("1");
            id(set_run_time).publish_state(25.0);
            id(set_warm_up_time).publish_state(03.0); //время разминки
            id(set_cool_down_time).publish_state(03.0); //время заминки
            id(remaining_run_time) = 25 * 60;
            id(manual_stop) = false;
          } else if (program == "HIIT") {
            // --- Устанавливаем зону по умолчанию при выборе---
            id(zone_select).publish_state("4");

            id(set_run_time).publish_state(0.0);      // время тренировки = 0
            id(remaining_run_time) = 0;               // не отсчитываем время
            id(set_warm_up_time).publish_state(0.0);  // при желании можно убрать разминку
            id(set_cool_down_time).publish_state(0.0);// и заминку, если они не нужны
            id(interval_phase) = "high";
            id(interval_time) = 0;
            id(manual_stop) = false;
          
          } else if (program == "Pulse Zone") {
            id(set_run_time).publish_state(30.0);
            id(set_warm_up_time).publish_state(03.0); //время разминки
            id(set_cool_down_time).publish_state(03.0); //время заминки
            id(manual_stop) = false;
          }


# Gender — выбор пола (Male/Female).
# При изменении обновляет Dual State Button на дисплее Nextion
# и запускает пересчёт пульсовых зон.
  - platform: template
    name: "Gender"
    id: gender_select
    restore_value: yes
    options:
      - "Male"
      - "Female"
    initial_option: "Male"
    optimistic: true
    on_value:
      - lambda: |-
          bool is_male = (id(gender_select).current_option() == "Male");
          id(display_nextion).send_command_printf("age.bt0.val=%d", is_male ? 0 : 1);
          ESP_LOGI("Nextion", "Gender synced: %s", is_male ? "Male" : "Female");

      - script.execute: update_heart_rate_zones

# Heart Rate Zone — выбор зоны пульса (1–5).
# При изменении запускает скрипт обновления зон.
  - platform: template
    name: "Heart Rate Zone"
    id: zone_select
    restore_value: no
    options:
      - "1"
      - "2"
      - "3"
      - "4"
      - "5"
    initial_option: "1"
    optimistic: true
    on_value:
      - script.execute: update_heart_rate_zones
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

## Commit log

2025-04-05 Update config.yaml
    esp32_ble_server:
    model: Treadmill Controller
    manufacturer: "ESP32-S3"
2025-04-13 Kinomap on iOS, FTMS statuses
    - Added FTMS support for Kinomap on iOS using shortened UUIDs.
    - Added support for FTMS statuses (Training Status / Fitness Machine Status).
    [config.yaml]
2025-05-29 Update config.yaml
    - May 29, 2025:
    - Added calculation of burned fat (in grams) to Workout Summary log.
    [config.yaml]
2025-06-08 Исправлены пути к файлам в документации и обновлены ссылки на руководства
2025-06-08 Исправлены пути к изображениям в документации для корректного отображения
2025-06-08 Обновлены ссылки на документацию FTMS в README.md и README.ru.md для корректного отображения
2025-06-08 Обновлены бинарные файлы для интерфейса тренажера Nextion
2025-06-08 Добавлены файлы дизайна печатной платы и бинарные файлы для дисплея Nextion
2025-06-08 Обновлены заголовки и описание в README.md и README.ru.md для улучшения ясности проекта и его возможностей
2025-06-08 Обновлены заголовки в README.md и README.ru.md для улучшения ясности проекта
2025-06-08 Обновлены ссылки на протокол FTMS в README.md и README.ru.md для улучшения ясности
2025-06-08 Добавлено новое содержание в оглавление README.md для улучшения навигации
2025-06-10 Добавлены жесты свайпа для дисплея Nextion для улучшения навигации между вкладками и экранами
2025-06-11 Обновлены параметры BLE и исправлены ссылки на обновление дисплея Nextion для улучшения функциональности
    [config.yaml]
2025-06-11 Переименование HMI и TFT дисплея Nextion 2.8
2025-12-17 feat: Add new incline profiles and enhance speed control algorithms
    - Introduced new incline profiles for Zwift routes including:
    - Ocean Blvd (11.2km)
    - Beach Island Loop (12.8km)
    - Hilly Route Reverse Run (9.2km)
    - Jon’s Route (12.6km)
    - Updated speed control algorithms with adaptive correction modes:
    - Soft, Precise, and Aggressive modes for different running styles.
    - Improved interval training logic with customizable cycles and durations.
    - Enhanced user interface on Nextion display for better navigation and usability.
    - Added automatic treadmill shutdown feature for motor overheating.
    - Integrated distance sensor for dynamic speed control and safety features.
    - Updated ch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
    [config.yaml]
2025-12-17 Добавлено упоминание о changelog в README и README.ru для улучшения навигации.
2025-12-17 fix: Обновлены ссылки на changelog в README и README.ru для корректного отображения
2025-12-17 fix: Исправлены ссылки на changelog в README и README.ru для корректного отображения
2025-12-17 fix: Исправлено форматирование ссылок на changelog в README и README.ru для улучшения читаемости
2025-12-17 fix: Обновлены пути к изображениям в README.ru и исправлена ссылка на changelog для корректного отображения
2025-12-17 Добавлены галерея изображений и видео в документацию README и README.ru для улучшения визуального восприятия
2025-12-17 Обновлены ссылки на видео в документации README и README.ru для улучшения доступа к контенту
2025-12-17 Обновлены заголовки разделов и добавлены изображения в документацию README и README.ru для улучшения визуального восприятия
2025-12-17 fix: обновлены ссылки на changelog в документации для согласованности между версиями
2025-12-17 Добавлены GIF-превью для Zwift в документацию README и README.ru для улучшения визуального восприятия
2025-12-17 Обновлены заголовки разделов и добавлены новые изображения в документацию README и README.ru для улучшения визуального восприятия и доступа к контенту
2025-12-17 fix: уточнены описания для дисплея Nextion и интеллектуальной регулировки пульса в документации
2025-12-17 fix: уточнено описание агрессивного режима коррекции скорости в документации
2025-12-18 fix: исправлено форматирование изображений в документации PCB для улучшения визуального восприятия
2025-12-18 fix: обновлено изображение PCB для улучшения визуального восприятия в документации
2025-12-18 fix: обновлены размеры изображений в документации для улучшения визуального восприятия
2025-12-18 fix: обновлены изображения в документации для улучшения визуального восприятия
2025-12-18 fix: исправлено форматирование изображений в документации для улучшения визуального восприятия
2025-12-18 Refactor code structure for improved readability and maintainability
    [FC33_speed_sensor_mount.stl, FC33_speed_sensor_mount_v2.stl]
2025-12-18 Добавлено: документация и файлы дизайна для 3D-печатного корпуса тредмила
    [treadmill_case.step]
2025-12-18 fix: обновлено описание работы датчика и размеры печати в документации
2025-12-18 fix: уточнено описание поддержки дополнительных обновлений в документации
2025-12-18 fix: обновлено описание содержимого папки с 3D-моделями для тредмила
2025-12-18 fix: уточнено описание статуса дизайна и удалены лишние детали о компонентах
2025-12-18 fix: уточнено описание дизайна и добавлены детали о 3D-печати
2025-12-18 fix: уточнено описание технологии печати для улучшения сцепления и текстуры
2026-06-10 feat: publish current treadmill config safely
2026-06-10 refactor: split treadmill config into local packages
    [10-hardware.yaml]
2026-06-10 tools: clarify route profile generation
    [11.1 Ocean Blvd 11.2km.csv, 5K loop 5.0km.csv, Beach Island Loop 12.8km.csv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]
2026-06-10 refactor: keep device setup in main ESPHome config
2026-06-10 refactor: streamline treadmill runtime updates
    [10-hardware.yaml]
2026-06-11 docs: highlight laser safety-zone sensing
2026-06-11 docs: flag UART protocol adaptation difficulty
2026-06-11 docs: add project support and power board roadmap
2026-10-18 route_profiles: 5K Loop — mark no elevation (source altitude only climbs 0→50 m at ~1 % on a closed loop; neighbouring roads carry the same broken altitude)
2026-10-23 Sync firmware 1.0.0-beta.4 and web UI sources from the live build
    - esphome/: package-based config (treadmill.yaml private, treadmill-public.yaml for releases),
    C++ includes, local esp32_ble_server and nextion components, generated treadmill_dashboard.h
    - web-ui/: page sources and generate.py (writes esphome/treadmill_dashboard.h)
    - tools/fw-release.sh: publishes firmware pre-releases and the OTA manifest
    - remove treadmill_workouts/ (recording and FIT export now run on the board)
    - remove old single-file config.yaml and incline_profiles.h
2026-10-23 Web UI fixes, browser demo and CI
    - presets: one highlighted preset, built-in HIIT presets carry speeds, HIIT presets keep warm-up/cool-down mode
    - HIIT/fartlek plan cards no longer stick after editing (DRUM flag reset)
    - progress week Mon-Sun, firmware Check button, separate update icons
    - 90-controls.yaml: HIIT settings survive reboot; 93-fw-update.yaml: Check Firmware Update button
    - web-ui/demo/mock.js: virtual treadmill for the GitHub Pages demo (generated/demo.html)
    - CI: header matches sources, JS syntax, FIT test, deploy demo to Pages
2026-10-23 Demo: sample Ufa routes; page sends a referrer so OpenStreetMap tiles load behind no-referrer proxies
2026-10-23 Demo: four sample workouts (pulse zone, map route, HIIT, fartlek); fix route selection in the demo
2026-10-23 History: a route workout is titled 'Маршрут · <route>' instead of 'Тренировка'
2026-10-25 docs: require ESP32-S3 N16R8 (16 MB flash, 8 MB octal PSRAM)
2026-10-25 docs: routes drawn on the map and saved on the board, workout compression and archive capacity, FIT export contents
2026-10-25 README: drop the power-board item from the roadmap
2026-11-01 Version 1.0.0-beta.7 + display 1.0.3: main page button ids for the new TFT, display HR picker and status bar, web UI state cache
    - Quick start and main tiles bound to the renumbered TFT ids (3..8); Fartlek tile renamed bfartlek; old page 11 bindings removed
    - Display: HR monitor search/select on Bluetooth page 19; main page time, heart rate and heart icon
    - Web UI: last known states cached in the browser, header badges/motor temperature/zone bar keep their place while live data arrives
    - Leak watch (Memory Trend / Memory Drop) and calmer low-memory diagnostics
2026-11-03 Device timezone Asia/Yekaterinburg; faster status bar refresh
2026-11-03 Time zone stored on the board: web UI computes POSIX offsets and DST rules, firmware applies them (display clock, records)
2026-11-06 Motor speed factor: multiply speed commands for motors that run slower than commanded; SPDMAX up to 40
2026-11-06 Release 1.0.0-beta.9: PWA, project-logo icon, motor speed factor; docs
2026-11-06 Docs: motor speed factor screenshot
2026-11-08 docs: link published PCB project and refresh bilingual overview
2026-11-14 docs: correct Nextion UART wiring diagram
